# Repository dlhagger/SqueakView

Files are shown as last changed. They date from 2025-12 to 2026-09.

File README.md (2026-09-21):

# SqueakView

SqueakView is a scientific FLIR capture, behavior logging, and YOLO26 pose
inference application for the NVIDIA Jetson Orin Nano. The current platform is
JetPack 7.2.1, CUDA 13.2, TensorRT 10.16, and DeepStream 9.1 using the
PyServiceMaker Pipeline API.

The current development baseline is one FLIR camera at 1440×1080 and 30 FPS,
with optional RP2040 serial triggering/logging and a batch-1 TensorRT pose
model. Generated engines are device-specific and are built locally on the
Jetson. The GUI's wider numeric ranges permit development experiments; they do
not imply scientific qualification. The checked-in production matrix supports
only its explicitly listed 1440×1080/30 FPS profile, and that profile remains
unqualified until the acceptance gates below are completed.

## Data-flow policy

SqueakView treats the compressed camera recording as scientific ground truth:

- The recording branch is non-leaky. It never intentionally drops a frame.
- Inference is downstream-leaky so slow inference cannot backpressure recording.
- GUI preview is leaky because it is only an operator spot check.
- Every recorded frame is reconciled against a durable source audit and the
  recording admission ledger.
- Missed live inference can be recovered later on downstream compute by
  replaying `raw.mp4`.

`raw.mp4` is H.264-compressed with CPU `x264enc`. It is authoritative, but not
an uncompressed sensor dump. CPU encoding is intentional because the Orin Nano
does not provide the hardware encoder used by larger Jetson modules.

## Acquisition and analysis boundary

The Jetson is the acquisition appliance. Normal shutdown validates the final
MP4 sample count against the durable capture, recording-admission, and
controller totals without rereading the multi-gigabyte ledgers. Frame-level
reconciliation, controller timing alignment, exploratory notebooks,
production-scale analysis, video transcoding, and offline re-inference are
explicit analysis work and do not block safe recording closure.

The current transfer procedure is a manual copy of the complete finalized run
directory. Keep the Jetson original until the DGX copy has been inspected and
validated. See [data_viz/README.md](data_viz/README.md) for the run contract,
manual transfer checklist, DGX directory layout, alignment commands, and
downstream data-handling rules. Resumable `rsync` transfer is flagged for a
future release and is not part of the initial workflow.

## Repository layout

```text
build_engine/                    Project Setup model-builder documentation
configs/                         Runtime tracker configuration
native/flir_gst_source/          Scientific Spinnaker GStreamer source
native/nvdsinfer_custom_impl_yolo/ DeepStream YOLO26 detector parser
resources/project_template/      New-project tasks, qualification, and model seeds
squeakview/apps/inference/        Live and offline PyServiceMaker pipelines
squeakview/apps/operator/         Qt operator GUI and run lifecycle
squeakview/common/                Run, profile, serial, and dashboard utilities
scripts/preflight.sh              Device/model readiness checks
scripts/align_run_outputs.py      Camera, video, inference, and TTL alignment
data_viz/README.md                Jetson-to-DGX transfer and analysis workflow
data_viz/analysis_demo_viz.ipynb Scientific run analysis and visualization
tests/                            Pure-Python and on-device pipeline tests
```

Application code and scientific data have separate ownership. Each project owns
its `runs/`, `models/`, `model_sources/`, `tasks/`, `profiles/`, and
`qualification/` directories outside this repository. The application install
is replaceable and normal operation does not write to it. New projects receive
independent copies of MouseHouse v2, stock YOLO pose, the default task, and the
qualification templates from `resources/project_template/`.

To build a model, put any additional `.pt` checkpoint and dataset YAML together
in a direct child of the project's `model_sources/` directory. Launch
SqueakView, select the project, and use the pre-acquisition **Project Setup**
screen. Generated device-specific packages are published only into that
project's `models/` directory.

## Install and update layout

Keep the Git checkout in Documents and let SqueakView create projects beside it:

```text
~/Documents/
├── SqueakView/           application code, `.venv`, and native builds
└── SqueakView Projects/  project settings, models, profiles, and runs
```

For a fresh checkout:

```bash
cd "$HOME/Documents"
git clone https://github.com/dlhagger/SqueakView.git
cd SqueakView
uv venv --python 3.12 --system-site-packages
uv sync
bash scripts/setup_jetson.sh
```

Reboot after the one-time setup. To update later, finish any active run, close
SqueakView, and update only the application checkout:

```bash
cd "$HOME/Documents/SqueakView"
git pull --ff-only
uv sync
bash scripts/build_native.sh
.venv/bin/python -m pytest -q
bash squeakview.sh
```

Routine application updates do not require a reboot. Git, dependency, and
native-build operations never target `~/Documents/SqueakView Projects`, so they
cannot replace scientific data. See [the project workflow](docs/PROJECT_WORKFLOW.md)
for project creation, model building, rollback, and acceptance checks.

## Jetson device setup

Run the device setup once as the desktop user who will launch SqueakView:

```bash
bash scripts/setup_jetson.sh
```

The script installs NVIDIA's Jetson FFmpeg package (including `ffprobe`) and
the complete GStreamer runtime/plugin and native build prerequisites, builds
both the FLIR GStreamer source and the
DeepStream YOLO parser against the installed CUDA toolkit, and adds that user
to the `dialout` group for RP2040/USB serial access. It also creates
`~/Documents/SqueakView Projects` when absent and leaves an existing directory
untouched. It can be launched from any working directory. Reboot after it
completes because a group change cannot affect an already-running login session.
If the whole setup script is invoked through `sudo`, it deliberately drops back
to the desktop user for native compilation so the checkout does not acquire
root-owned build files. Do not run the application itself with `sudo`.

After the one-time privileged setup, checkout updates rebuild their native
components without sudo through `bash scripts/build_native.sh`.

## Platform prerequisites

Install these before setting up the repository:

- JetPack 7.2.1 with CUDA/TensorRT
- NVIDIA DeepStream 9.1 at `/opt/nvidia/deepstream/deepstream`
- FLIR/Teledyne Spinnaker SDK at `/opt/spinnaker`
- [Spinnaker for the JetPack 7.2 series](https://teledyne.app.box.com/s/ccj73r4xu8rusbnu12pytcisbexdchfa)
  is currently distributed as a beta build by Teledyne and is deployed here on
  JetPack 7.2.1.
- GStreamer runtime and development headers
- Jetson Orin Nano specific install of FFmpeg (`scripts/setup_jetson.sh` installs it)
- CMake, a C++ compiler, and `uv`

Typical native-build packages:

```bash
sudo apt install build-essential cmake pkg-config \
  libgstreamer1.0-dev libgstreamer-plugins-base1.0-dev
```

Expected vendor paths:

```text
/opt/spinnaker/include
/opt/spinnaker/lib
/opt/nvidia/deepstream/deepstream/sources/includes
/usr/local/cuda-13.2
```

Override the DeepStream root when necessary:

```bash
export SQUEAKVIEW_DEEPSTREAM_SDK=/opt/nvidia/deepstream/deepstream
```

## Python environment

SqueakView targets Python 3.12 on Linux AArch64. Create the project environment
with access to the JetPack/DeepStream system packages:

```bash
uv venv --python 3.12 --system-site-packages
uv sync
source .venv/bin/activate
```

The project uses CUDA 13.2 PyTorch wheels and a CUDA 13 ONNX Runtime index as
configured in `pyproject.toml`. DeepStream 9.1 supplies PyServiceMaker through
the system Python installation.

The live tensor decoder currently uses PyTorch DLPack to read DeepStream tensor
metadata. DeepStream performs TensorRT inference; ONNX Runtime is used by model
export tooling rather than by the live pipeline.

## Build native components

### FLIR GStreamer source

```bash
cmake -S native/flir_gst_source -B native/flir_gst_source/build
cmake --build native/flir_gst_source/build -j
GST_PLUGIN_PATH=$PWD/native/flir_gst_source/build gst-inspect-1.0 flirspinsrc
```

This produces `native/flir_gst_source/build/gstflirspinsrc.so`.

`flirspinsrc` uses Spinnaker directly and emits `GRAY8` frames. Its scientific
metadata profile records the FLIR chunk frame ID, acquisition-local image ID,
camera timestamp, exposure, gain, black level, ROI, pixel format, sequencer
state, CRC, image status, payload size, host clocks, camera/host clock
correlation, temperature, and transport counters. Incomplete images fail the
acquisition instead of being silently accepted.

See [native/flir_gst_source/README.md](native/flir_gst_source/README.md) for the
standalone camera smoke tests and complete metadata contract.

### DeepStream YOLO parser

Build against the CUDA version installed on the device:

```bash
make -C native/nvdsinfer_custom_impl_yolo CUDA_VER=13.2 -j
```

This produces:

```text
native/nvdsinfer_custom_impl_yolo/libnvdsinfer_custom_impl_Yolo.so
```

The library satisfies DeepStream's detector parser ABI for the YOLO26
end-to-end output. The PyServiceMaker `Yolo26PoseTensorOperator` is the
authoritative pose decoder: it reads `output0` tensor metadata, applies the
model-sidecar thresholds, restores source-image coordinates, and hands objects
and keypoints to NvDCF tracking and CSV persistence.

Rebuild both native components after JetPack, CUDA, TensorRT, DeepStream, or
Spinnaker upgrades.

## Build a YOLO26 pose model package

Fresh projects contain model inputs but no generated TensorRT packages. Launch
SqueakView normally:

```bash
bash squeakview.sh
```

After project selection, Project Setup defaults to the project-owned MouseHouse
v2 source package. Its isolated builder worker holds the project's exclusive
writer lock and:

1. Reads standard class names, keypoint names, and keypoint shape from the YAML
   and checkpoint without modifying the YAML.
2. Passes the YAML to `Ultralytics.export(data=...)`.
3. Exports an NMS-free, end-to-end FP16 or FP32 TensorRT engine on the target
   Jetson using Ultralytics `nms=False`.
4. Strips the Ultralytics metadata prefix to produce the raw TensorRT plan
   expected by DeepStream.
5. Validates ONNX and TensorRT input/output shapes.
6. Writes and validates a schema-3 model package with a schema-2 pose sidecar.
7. Exits and releases its CUDA context before the acquisition supervisor starts.

Generated layout:

```text
$SQUEAKVIEW_PROJECT/models/<model_name>/
  weights/<source>.pt
  onnx/<model>_<precision>_b<batch>.onnx
  engines/<model>_<precision>_b<batch>.engine
  labels/classes.txt
  labels/labels.txt
  configs/<model_name>.txt
  configs/<model_name>.pose.json
  validation/import_report.json
  model.yaml
```

The pose sidecar contains tensor geometry, class thresholds, tracking policy, and keypoint labels. SqueakView stores and displays labeled keypoint dots.

TensorRT plan files are device-specific. Build each engine on the Jetson that
will run it. The model package batch size must match the configured camera
count. The currently validated packages and normal GUI workflow are batch 1.
Multi-camera support is planned, you may implement it now at your own risk by
matching the batch size to the number of configured cameras.

Each run manifest records SHA-256 identities for the model manifest, pose
sidecar, ONNX graph, DeepStream config, and TensorRT engine. Production
qualification requires the complete identity set and the exact installed
`nvidia-jetpack` package version is retained with the other platform packages.

See [build_engine/README.md](build_engine/README.md) for builder details.

## Preflight

Select a generated model explicitly and run preflight with the project
interpreter:

```bash
export SQUEAKVIEW_PROJECT="$HOME/Documents/SqueakView Projects/My Project"
PYTHON_BIN=.venv/bin/python \
SQUEAKVIEW_MODEL_NAME=<model_name> \
bash scripts/preflight.sh
```

You can provide the config directly instead:

```bash
PYTHON_BIN=.venv/bin/python \
DS_CFG="$SQUEAKVIEW_PROJECT/models/<model_name>/configs/<model_name>.txt" \
bash scripts/preflight.sh
```

Run the same check remotely:

```bash
ssh -t jetson@<jetson-host> 'cd ~/Documents/SqueakView && export SQUEAKVIEW_PROJECT="$HOME/Documents/SqueakView Projects/My Project" && PYTHON_BIN=.venv/bin/python SQUEAKVIEW_MODEL_NAME=<model_name> bash scripts/preflight.sh'
```

For camera-only testing without inference:

```bash
PYTHON_BIN=.venv/bin/python INFERENCE_ENABLED=0 bash scripts/preflight.sh
```

For a manual check of the configured controller as well, provide its device:

```bash
SQUEAKVIEW_MODEL_NAME=<model_name> SERIAL_ENABLED=1 \
SERIAL_PORT=/dev/ttyACM0 PYTHON_BIN=.venv/bin/python bash scripts/preflight.sh
```

Preflight checks the DeepStream install, required GStreamer elements, the FLIR
plugin and capture-ledger API, NvDCF dependencies, the selected model package,
Jetson memory state, `ffprobe`, and Python imports. It exercises DeepStream
9.1 Stream multiplexer 2 through the same VIC-to-surface-array NVMM path used
by acquisition. Before every recording, it also
creates a temporary 30-frame H.264 clip and fully decodes it through the same
isolated `nvv4l2decoder` used for anomaly escalation. Acquisition is
blocked if the Jetson hardware decoder cannot complete that real decoder
self-test. No readiness result is reused across recordings.

Inference preflight requires a schema-3 engine build identity matching the
current TensorRT, CUDA, Jetson Linux, GPU capability, and device. A schema-2
package remains readable for migration inspection but is blocked from
scientific acquisition; rebuild it from the Project Setup screen.

DeepStream may print plugin-scanner warnings for unused optional plugins when an
OpenTelemetry library is absent. They do not affect SqueakView if every required
element passes preflight. Preflight reports the current `tegrastats` sample for
diagnosis. NVIDIA documents its LFB field as an allocator statistic whose largest
normal block is at most 4 MB, so LFB is not treated as a standalone readiness
threshold.

See [`docs/REFACTOR_PLAN.md`](docs/REFACTOR_PLAN.md) for the staged JetPack 7.2.1
and DeepStream 9.1 modernization plan and the scientific recording invariants.

Note: clearing memory cache and setting the jetson to "cool" thermal profiles are
easily achieved by installing jtop.

## Launch the operator GUI

```bash
bash squeakview.sh
```

The small project chooser appears on every launch and preselects the most
recently opened valid project. You can create a project, browse to another one,
or confirm the preselected project. It creates the default projects parent when
missing and never rewrites an existing one. Project Setup then lets you build or
select the project default model before the supervisor, experiments, or subjects
start. For automation or development, pass an existing project explicitly:
`bash squeakview.sh /absolute/project/path`; Project Setup still appears.

This detached launcher is the production path. It starts a Qt-free supervisor,
which owns the controller, capture, run lock, and finalization while launching
and monitoring the required GUI. If the GUI exits or loses its exclusive IPC
lease during a run, the supervisor stops acquisition and completes fail-closed
finalization; acquisition never continues headlessly. Terminal or VS Code loss
does not end the supervised session. Separate bounded GUI and supervisor logs
are written under `${XDG_STATE_HOME:-$HOME/.local/state}/SqueakView/logs/`;
each mirror is capped at 32 MiB and partial
lines are capped at 64 KiB.
Stop requests are acknowledged immediately by the supervisor. Capture closure
and post-run analysis continue in a supervisor-owned worker while the responsive
GUI receives lifecycle events and heartbeats; run duration therefore cannot
turn a slow alignment pass into an IPC timeout or a false GUI-loss failure.
The launcher reports success only after the supervisor has authenticated the
GUI's IPC connection; an early GUI failure or connection timeout returns
nonzero with the supervisor log path. The bounded wait defaults to 35 seconds,
slightly longer than the supervisor's 30-second GUI connection deadline,
and can be adjusted with `SQUEAKVIEW_LAUNCH_TIMEOUT_S`.

The lease is renewed only by a Qt-main-loop timer, so a frozen GUI is treated
as lost even if its background IPC thread still exists. The DeepStream capture
child also uses Linux parent-death signaling, preventing a hard supervisor
failure from leaving the sessionized capture process alive. A hard owner failure
cannot perform ordered finalization, and that run must not pass qualification.

The RP2040 is a separate safety boundary. This repository currently contains no
versioned controller firmware or qualified negotiated watchdog, so an
independently powered controller may continue generating TTL pulses after total
Jetson/supervisor failure. Triggered scientific deployment requires a
firmware-level, hardware-qualified lease/watchdog before that failure mode can
be claimed safe. The proposed wire contract, host integration requirements, and
electrical acceptance evidence are defined in
[`docs/CONTROLLER_WATCHDOG_PROTOCOL.md`](docs/CONTROLLER_WATCHDOG_PROTOCOL.md).
The host includes an explicitly opt-in, production-disqualified experimental v1
implementation for firmware development and bench testing. Legacy behavior is
unchanged by default, and the application does not claim watchdog protection.

The complete project layout, model-build handoff, path ownership rules, and
short on-device acceptance pass are in
[`docs/PROJECT_WORKFLOW.md`](docs/PROJECT_WORKFLOW.md).

Direct GUI startup is blocked by default because it bypasses durable
supervision. For foreground development only, opt in visibly and provide an
explicit project:

```bash
SQUEAKVIEW_PROJECT="/absolute/path/to/My Project" \
SQUEAKVIEW_ALLOW_INPROCESS_BACKEND=1 \
.venv/bin/python squeakview_gui.py
```

Scientific operation must use `bash squeakview.sh`. Serial capture defaults to
`/dev/ttyACM0` at 115200 baud; choose the actual device shown by
`ls /dev/ttyACM*`.

Useful path overrides:

```bash
export SQUEAKVIEW_DEEPSTREAM_SDK=/opt/nvidia/deepstream/deepstream
export SQUEAKVIEW_PROJECTS_DIR="$HOME/Documents/SqueakView Projects"
bash squeakview.sh /absolute/path/to/a/project
```

The supervised backend launches inference first. For free-running capture, the
GUI reports recording after the PyServiceMaker pipeline reaches `PLAYING`. In
triggered mode, it sends `START` only after that readiness signal and reports
recording only after the first controller TTL is observed. The default readiness
timeout is 30 seconds and can be changed with
`SQUEAKVIEW_INFERENCE_READY_TIMEOUT`.

Serial logging may remain enabled during free-running capture, but its data are
auxiliary and no trigger/frame alignment is claimed. Exact TTL alignment is a
mandatory finalization and qualification gate only when both serial logging and
camera triggering are enabled under the legacy controller protocol. Protocol v2
is the production default for controller-backed GUI runs. A deliberate
`SQUEAKVIEW_CONTROLLER_PROTOCOL=legacy` override remains available only for
non-production bench development with older firmware.

Protocol v2 is negotiated before the clock preflight and capture launch. The
idempotent negotiation supports a freshly booted v1 controller and a controller
that remained in v2 after an earlier run; idle `TIME_SYNC` and `SET_RTC`
responses then use reliable v2 framing. Controller frames are CRC checked and stored, with an `fsync`, in
`diagnostics/controller_v2.jsonl` before SqueakView sends a cumulative
`ACK_EVENTS`. The controller can then release the acknowledged RAM records.
Camera timing uses `CAMERA_EPOCH`, periodic `CAMERA_CHECKPOINT`, and
`CAMERA_STOP` rather than two serial lines per frame. A transport integrity
fault, conflicting replay, unrecoverable sequence gap, or controller reboot
during a run fails the run closed. `serial.csv` remains a compatibility export
of decoded payloads; the JSONL journal is the v2 source of truth.

Run the physical-controller qualification before production use:

```bash
uv run mousehouse-protocol-v2-test /dev/ttyACM0 \
  --fps 30 --duration 60 --withhold-acks 5 \
  --request-resend --status --correct-clock --verbose \
  --output /tmp/mousehouse-protocol-v2-test
```

`--correct-clock` explicitly authorizes one idle `SET_RTC` if the initial clock
burst is outside tolerance. The tool always collects and verifies a fresh
seven-sample burst after correction before it may start acquisition.

The controller remains in v2 until it reboots. SqueakView safely rejoins that
mode on subsequent GUI runs, so a reboot between ordinary runs is unnecessary.
Reboot after a standalone qualification before using a host build that predates
this idempotent negotiation support.
The separate `--exercise-overflow-failsafe` mode intentionally fills the queue,
invalidates and stops the run, and also requires a reboot. Do not use it during
an experiment.

The durable backend, not the GUI, owns the required preflight gate. It records a
hashed, structured result in both run status and manifest metadata; a missing
FFmpeg check, skipped/failed preflight, or indeterminate automatic-suspend
policy cannot qualify as scientific production. This also prevents direct IPC
clients from bypassing the check.

For every controller-backed experiment, startup also validates the MouseHouse
controller RTC through the already-open serial transport before capture is
launched or controller `START` is sent. The controller uses the PCF8523 as its
sole RTC. Never attach a DS3231 at the same time: both chips have the fixed I²C
address `0x68`. SqueakView first requires the Jetson to report NTP
synchronization, then collects seven `TIME_SYNC` exchanges approximately 100 ms
apart. All seven must report `RTC_VALID`; the median offset of the three
lowest-round-trip samples must be within ±1.5 seconds.

If the clock is invalid or outside tolerance, acquisition remains blocked. RTC
correction is available only when **Allow one pre-run controller RTC correction**
was explicitly enabled in run configuration. SqueakView then sends one
whole-second `SET_RTC`, requires its acknowledgement, and validates a completely
new seven-sample burst. An already-passing clock is never corrected. Validation
and correction are prohibited while a controller session or feed is active;
`DEVICE_BUSY`, timeouts, malformed responses, and NACKs all fail closed. The
complete record is saved as `diagnostics/clock_validation.json`, referenced by
run status and `run_manifest.json`, and summarized in the GUI's Clock Preflight
section.

The RTC establishes UTC only before the experiment. During acquisition, event
timestamps remain anchored to the RP2040 monotonic clock; SqueakView performs no
continuous RTC synchronization and does not alter session timestamp formats.

Startup and the capture child enforce the same free-space reserve (1 GB by
default). During long runs the child rechecks it every five seconds and requests
a fatal but orderly EOS/container close before the filesystem is exhausted.
Set a larger experiment-appropriate reserve with
`SQUEAKVIEW_MIN_RUN_FREE_BYTES`; `SQUEAKVIEW_STORAGE_CHECK_INTERVAL_S` controls
the check interval. Both resolved values are recorded in `run_manifest.json`.

Only one SqueakView process may own scientific acquisition at a time. The
backend holds an OS-managed lock in the run store from pre-start through final
status persistence. A second GUI receives an explicit refusal; a crashed
process releases the lock automatically, so the presence of the small lock file
alone does not indicate an active run.

The timeout is a maximum wait for pipeline readiness, not a fixed warm-up delay.
Reducing it may reject a healthy pipeline that needs longer to load the engine
and enter `PLAYING`.

The run header remains fixed while the operator workspace is composed from
native Qt cards. Open **Layout** while idle to unlock card dragging/floating,
save the current arrangement immediately, or restore the versioned default;
card dividers remain resizable, and a clean GUI close also saves the current
arrangement. Card movement and reset are locked during startup, recording, and
finalization, while explicit Save remains available. Right-click any card title
to open Qt's unified checklist for showing or hiding every card, including Live
Task State and Operator Events. The capture-health panel
shows recording backlog, camera transport health, frame/drop counters, and the
current stop/finalization stage. Run identity and elapsed state remain visible
while the independent post-run finalizer is working.

The capture child's DeepStream output is also retained in
`diagnostics/deepstream.log` inside each run. This log is capped at 64 MiB so a
verbose debug profile cannot consume storage without bound; the operator log
continues after the cap is reached. With
`SQUEAKVIEW_DEEPSTREAM_DEBUG_PROFILE=1`, the run manifest records the profile
and any NVIDIA frame/component latency output is retained in that diagnostic
log. The environment variables alone do not prove that a custom Service Maker
graph emits latency records. The qualification exception therefore fails
unless a bounded scan finds both NVIDIA's structured `Source id`/`Frame_num`/
`Frame latency` record and its `Comp name`/`Component latency` record, with
finite values, and the diagnostic log was not truncated.
The profile remains qualification-only until paired debug-off/debug-on runs
establish its acquisition overhead. Debug-profile runs are explicitly marked
non-production. Qualify only the debug-on member with the narrow exception:

```bash
export SQUEAKVIEW_PROJECT="/absolute/path/to/My Project"
.venv/bin/python scripts/qualify_run.py "$SQUEAKVIEW_PROJECT/runs/<debug-off-run>"
.venv/bin/python scripts/qualify_run.py "$SQUEAKVIEW_PROJECT/runs/<debug-on-run>" --allow-debug-profile
```

After both matched runs pass `scripts/qualify_run.py`, compare their bounded
recording and system metrics with:

```bash
.venv/bin/python scripts/compare_debug_overhead.py \
  "$SQUEAKVIEW_PROJECT/runs/<debug-off-run>" "$SQUEAKVIEW_PROJECT/runs/<debug-on-run>" \
  --thresholds "$SQUEAKVIEW_PROJECT/qualification/<approved-overhead-limits>.yaml" \
  --output "$SQUEAKVIEW_PROJECT/qualification/debug-overhead.json"
```

Follow the complete non-automating acquisition and evidence-retention procedure
in [docs/qualification/DEBUG_OVERHEAD_PROTOCOL.md](docs/qualification/DEBUG_OVERHEAD_PROTOCOL.md).
The checker accepts `--case-id` to require both GUI-launched runs to carry the
same backend-enforced qualification binding, and rejects nonterminal or
non-supervised runs.

The comparison fails closed unless the capture, inference, preview, model,
power-mode, application-commit, and complete platform/package/native-plugin
identities match and the manifests explicitly identify opposite debug-profile
states. It compares all five model content
hashes and the engine build identity, verifies that neither cached qualification
summary is stale against its hashed source artifacts, requires the same exact
validated limits file, and requires duration to differ by no more than the
larger of five seconds or 1% of the longer run (both tolerances are CLI options).

Without `--thresholds`, a comparable report remains `incomplete`; the tool does
not invent empirical limits. A version-1 threshold file must set `approved:
true` and provide every reported metric under `metrics`, with at least one
nonnegative `max_increase` or `max_percent_increase` per metric. These bounds
apply only to increases from debug-off to debug-on. An approved profile makes
the report and command exit explicitly passed or failed.

## Live DeepStream pipeline

The validated single-camera path is:

```text
flirspinsrc → GRAY8 caps → tee
  ├─ record queue (120 frames / 4 s minimum, non-leaky)
  │    → x264enc (native GRAY8) → h264parse → mp4mux → raw.mp4
  └─ inference queue (32 frames, downstream-leaky)
       → VIC nvvideoconvert/surface-array NVMM-NV12 → nvstreammux v2
       → nvinfer/TensorRT → Python YOLO26 pose decode
       → CUDA NvDCF → [nvosdbin → nvstreamdemux when preview is enabled]
       → preview admission identity → preview queue (1 frame, downstream-leaky)
       → preview delivery identity → nvunixfdsink
       → Qt nvunixfdsrc preview
```

The FLIR transport is configured with at least 64 host buffers (two seconds at
30 FPS), and the record queue intentionally backpressures rather than discarding
data. Recording backlog is sampled in `diagnostics/recording.csv`; a sustained
three-second backlog fails the run before the four-second queue can fill. If CPU
encoding cannot sustain acquisition, the run therefore stops with explicit
evidence instead of silently producing a plausible but incomplete video.

This contract proves temporal frame completeness, not pixel-lossless storage.
The current `x264enc` profile is bitrate-controlled H.264 with one reference
frame, adaptive quantization disabled, no B-frames, and no lookahead. It is explicitly
recorded as `pixel_fidelity: lossy` in `run_manifest.json`. Do not use it for an
experiment requiring exact source pixels until a separately named lossless/raw
profile has been implemented and throughput-qualified.

SqueakView fails a run explicitly when it cannot preserve timing and data
integrity. It does not silently continue with an incomplete but plausible video.
The current production candidate has completed a validated 16-hour,
1,707,205-frame run at 1440×1080 and 30 FPS with zero recording drops, frame
gaps, inference skips, or TTL mismatches.

The GUI/runtime can construct multiple camera branches, producing `raw.mp4` for
camera zero and `raw_camN.mp4` for additional cameras. Multi-camera inference
also requires a batch-N model package and has not received the same scientific
validation as the single-camera path. 

Multi-camera operation remains an advanced configuration and should not be used
for production acquisition until it receives equivalent long-run validation.

SqueakView uses the CUDA NvDCF tracker in `configs/tracker_mouse_nvdcf.yml`.
Jetson Orin Nano has no PVA hardware, so a PVA/VPI tracker profile is not an
acceleration option. Tracker thresholds remain model- and experiment-specific.

## Run outputs and frame identity

Runs are stored under:

```text
runs/<experiment>/<subject>/<subject>_<timestamp>_<shortid>/
```

Important outputs include:

```text
raw.mp4                         Authoritative compressed camera recording
frames.csv                      Authoritative recorded-frame ledger
serial.csv                      RP2040 events, TTLs, markers, and host clocks
objects.csv                     Detector/tracker object rows
keypoints.csv                   Normalized pose keypoints
run_manifest.json               Configuration, model identity, and artifacts
run_status.json                 Lifecycle, reconciliation, and validation
alignment_summary.json          Compact frame/video/controller audit
diagnostics/camera.csv          Temperature and transport health samples
diagnostics/recording.csv       Recording queue and encoder telemetry
diagnostics/system.csv          Capture-owned bounded Jetson resource telemetry
diagnostics/errors.csv          Camera gaps, CRC, and incomplete-frame events
diagnostics/camera_runtime.json Camera identity and clock calibration
diagnostics/deepstream.log      Size-bounded capture/DeepStream child output
diagnostics/post_run.log        Finalizer subprocess log
diagnostics/preview_admission*.csv Source IDs entering each leaky preview queue
diagnostics/preview_delivery*.csv  Source IDs delivered after preview shedding
config/task.yaml               Immutable run-local task definition snapshot
```

`frames.csv` is written live by the FLIR source and is the source of truth for
captured frame identity. It contains one row per emitted source buffer. Stop
uses bounded tail reads and the MP4 sample table; it does not rebuild this file.
Validation requires its final index to agree with the non-leaky recording
admission ledger and the finalized MP4 sample count.
The camera telemetry, error ledger, and runtime snapshot are also written by
the source while acquisition is active, rather than reconstructed at shutdown.
`objects.csv` is the single object-observation table; track summaries are
derived from it when analyzed.
Once a run reaches a terminal state, its acquisition, model, Git, and storage
provenance in `run_manifest.json` is immutable. Later bottle entry updates only
the bottle summary, artifact inventory, and manifest update timestamp.

Source, admission, and inference ledgers (`capture_cam*.jsonl`,
`record_admission*.csv`, and `inference/`) are retained after successful
validation as primary scientific provenance. Only transient finalizer progress
state is cleaned up. This costs additional storage but preserves the evidence
needed to reproduce frame reconciliation and diagnose a later integrity issue.
Routine finalization reads the bounded MP4 sample tables without parsing or
decoding the complete H.264 stream. It requires the sample-size, timing, and
sample-to-chunk totals to agree with the live frame manifest, source ledger,
recording-admission ledger, and controller count. Full decode remains an
explicit qualification option, not an automatic shutdown fallback.

Generate a bounded-memory qualification summary after finalization with:

```bash
export SQUEAKVIEW_PROJECT="/absolute/path/to/My Project"
.venv/bin/python scripts/qualify_run.py "$SQUEAKVIEW_PROJECT/runs/<experiment>/<subject>/<run>"
```

The checked-in JetPack 7.2.1 limits profile is intentionally marked
measurement-only. Results remain `incomplete` until sustained baseline runs are
used to approve explicit thermal, resource, telemetry-coverage, and recording
limits. Qualification writes `qualification_summary.json`; it never changes the
capture-validity decision in `run_status.json`. The summary hashes the manifest,
status, limits, primary recording artifacts, system telemetry, and every
recording telemetry file it consumed so paired comparisons reject stale or
substituted evidence.
Preview admission and delivery ledgers attribute intentional GUI-preview
shedding by source sequence, camera FrameID, and PTS. Missing preview evidence
fails preview-enabled qualification, but preview loss and preview-observability
failure never invalidate the independent scientific recording.

The full 24-cell short/one-hour/full-duration matrix is defined in
`$SQUEAKVIEW_PROJECT/qualification/matrix.v1.yaml` across inference, preview, and 25 W/MAXN_SUPER
modes. The complete operator procedure, including hardware prerequisites,
measurement-only limits, durable campaign outputs, and recovery from incomplete
cells, is in [docs/qualification/QUALIFICATION_WORKFLOW.md](docs/qualification/QUALIFICATION_WORKFLOW.md).
Enumerate the canonical IDs and create a non-overwriting assignment checklist:

```bash
.venv/bin/python scripts/qualify_matrix.py --list-cases
.venv/bin/python scripts/qualify_matrix.py \
  --init-assignments "$SQUEAKVIEW_PROJECT/qualification/assignments.local.yaml"
```

Print the next unassigned case, its exact environment, and a copyable terminal
launcher command without changing the checklist or starting hardware:

```bash
.venv/bin/python scripts/qualify_matrix.py \
  "$SQUEAKVIEW_PROJECT/qualification/assignments.local.yaml" \
  --next-case
```

After each completed run, record its case with `--assign`, then evaluate matrix
coverage with:

```bash
.venv/bin/python scripts/qualify_matrix.py \
  "$SQUEAKVIEW_PROJECT/qualification/assignments.local.yaml" \
  --assign '<case-id>' '/absolute/path/to/completed/run'
.venv/bin/python scripts/qualify_matrix.py "$SQUEAKVIEW_PROJECT/qualification/assignments.local.yaml"
```

For the acquisition itself, export
`SQUEAKVIEW_QUALIFICATION_CASE_ID='<case-id>'` before launching the operator.
The backend rejects factor, preview, or exact nvpmodel mismatches before run
creation and persists the binding. `SQUEAKVIEW_QUALIFICATION_MATRIX` may point
to a deliberately selected alternate versioned matrix. Ordinary runs remain
unbound when the case variable is unset; they cannot later be substituted into
the production matrix.

The assignment YAML must be a stable regular file; its read is size-bounded and
duplicate-key rejecting, and it rejects case IDs that are not present in the
selected matrix. The same stable, bounded regular-file policy applies to limits,
matrix, failure-plan, and debug-threshold inputs.

Unassigned cells and runs evaluated against measurement-only limits remain
`incomplete`; factor mismatches or failed run qualification fail the cell. The
matrix also fails closed on dirty/non-production runs and requires every cell
to use the same application commit and complete device/package/native-plugin
identity, including inference-off cells. Power modes must match the exact
labeled `nvpmodel` mode. Every inference-enabled cell must use the same hashed
model/engine identity.

After all cells pass against reviewed limits, create and verify the bounded,
content-addressed campaign inventory described in the workflow with
`scripts/archive_qualification_campaign.py`. The tool does not copy or modify
run data; it rejects incomplete campaigns and verifies the separately copied
archive tree byte-for-byte.

The destructive bench procedure for validating behavior after sudden input
power loss is documented in
[`docs/qualification/HARD_POWER_LOSS_PROTOCOL.md`](docs/qualification/HARD_POWER_LOSS_PROTOCOL.md).
The gated boundary-fault procedure and supported plan schema are documented in
[`docs/qualification/FAILURE_INJECTION_PROTOCOL.md`](docs/qualification/FAILURE_INJECTION_PROTOCOL.md).

The FLIR chunk `FrameID` is stored as `camera_frame_id` and increments for every
acquired image. The legacy aligner derives a per-run offset between that hardware
frame sequence and RP2040 `CAMERA_HIGH` counts. Protocol-v2 runs preserve camera
epoch/checkpoint/stop anchors for later pandas-based alignment on the analysis
device without emitting per-frame controller edges.

On stop, SqueakView asks the controller to stop before draining DeepStream and
keeps the serial reader open for final acknowledgements. After the capture
process confirms EOS and closes `raw.mp4`, the shutdown validator reads the
last monotonic indices from the capture and non-leaky recording-admission
ledgers, reads the MP4 sample-size/timing/sample-to-chunk/chunk-offset tables,
and requires all totals (plus the controller total when triggered) to agree.
These are bounded tail/table reads; normal shutdown does not hash or decode the
complete video and never rebuilds `frames.csv`. Legacy triggered runs then
generate the controller/camera alignment summary automatically from the
already-written manifest and serial ledger. Protocol-v2 runs validate recording
and acquisition counts on-device and leave detailed controller/camera alignment
to the analysis workflow. Structural errors and count mismatches fail directly.
Set
`SQUEAKVIEW_VIDEO_VALIDATION_FULL_DECODE=1` for qualification runs that require
every pixel frame to be decoded. Add `SQUEAKVIEW_VIDEO_VALIDATION_AB_VERIFY=1`
to run both full decoders and reject any count disagreement.
Bottle intake is calculated as initial minus final weight. A final weight above
the initial weight is saved but shown as a plausibility warning.

To rerun the legacy bounded-memory recovery reconstruction explicitly:

```bash
.venv/bin/python -m squeakview.apps.inference.post_run /path/to/run \
  --camera-count 1 --full-analysis --enable-infer --align
```

The command rebuilds `frames.csv` from recovery ledgers and performs the deeper
inference/object reconciliation. Normal runs do not need this command because
capture writes `frames.csv` live and Stop generates `alignment_summary.json`.

## Analyze a run

Copy the complete finalized run directory to the DGX Spark before beginning
downstream analysis. The source copy should remain unmodified; figures, tables,
new alignment results, and future re-inference outputs belong in a separate
analysis-results directory.

The visualization notebook is a short-run example of the current tables and
their timing relationships, not the production engine for a full-length run.
Launch it on the DGX from an analysis environment:

```bash
jupyter lab data_viz/analysis_demo_viz.ipynb
```

Set `RUN_DIR` in the first code cell to an explicit copied run. Leave
`INFERENCE_RESULT = "live"` to inspect the acquisition-time objects and
keypoints.

The notebook reports acquisition and inference health, TTL/PTS timing,
behavioral events, mapping provenance, NvDCF tracks, keypoint confidence, event-
locked object data, and an optional exact-frame `raw.mp4` preview with boxes and
keypoint dots.

The current notebook loads canonical CSVs into memory and is intended for short
or sampled demo runs. Do not run it on the acquisition Jetson or point it at a
complete 16-hour run. See [data_viz/README.md](data_viz/README.md) for the full
workflow and source-data rules.

## Offline re-inference (downstream only)

Do not run offline re-inference on the acquisition Jetson. On a downstream
system with a compatible TensorRT engine, launch it with:

```bash
python -m squeakview.apps.inference.offline RUN_DIR --cfg MODEL_CONFIG \
  --out-dir NEW_DERIVED_DIRECTORY
```

The command keeps the long-run frame ledger in a temporary disk-backed index
and performs one authoritative decode. It does not do a second full-file
FFprobe count pass: the in-pipeline audit requires contiguous decoded ordinals,
rejects frames beyond the ledger immediately, and only publishes a complete
manifest after decoder EOS and an exact final count. A small supervisor process
owns the native Service Maker worker. SIGINT/SIGTERM requests orderly teardown;
if native `stop()`/`wait()` remains blocked for 45 seconds, the supervisor
terminates the isolated worker process group and returns failure. Linux
parent-death containment also kills the worker if the supervisor itself dies.
Derived output never overwrites the acquisition `raw.mp4`, `objects.csv`, or
`keypoints.csv`.
See [data_viz/README.md](data_viz/README.md) for downstream source-data rules.

## Diagnostics

Show optional DeepStream plugin warnings that the GUI normally filters:

```bash
SQUEAKVIEW_SHOW_PLUGIN_WARNINGS=1 bash squeakview.sh
```

Request fan control when the current user has the required privileges:

```bash
SQUEAKVIEW_SET_FAN=1 bash squeakview.sh
```

Temporarily bypass GUI preflight only for deliberate diagnosis:

```bash
SQUEAKVIEW_SKIP_PREFLIGHT=1 bash squeakview.sh
```

Any run started with this bypass is explicitly marked non-production and cannot
pass qualification.

Qualification-only failure injection requires both an explicit safety gate and
a versioned JSON plan. Every such run is labeled `production_eligible: false`
in status and manifest metadata. Never enable this for data collection:

```bash
SQUEAKVIEW_ENABLE_FAILURE_INJECTION=1 \
SQUEAKVIEW_FAILURE_PLAN=/absolute/path/to/failure-plan.json \
bash squeakview.sh
```

Supported boundaries are the FLIR source, non-leaky recording queue, encoder,
muxer, filesink/disk, serial controller, and shutdown supervisor. The plan is
rejected if the gate is absent, its schema is unknown, or its target/kind is
unsupported.

The `/dev/full`-based `filesink/disk_full` case is intentionally immediate: it
fails on the selected sink's first write and requires `after_frames: 1` as a
sentinel. It does not simulate one successful recorded frame followed by disk
exhaustion. Use `filesink/error` when a delayed filesink-boundary fault is
required.

To exercise the required preview-off qualification cell while still using the
GUI as the operator interface, launch with `SQUEAKVIEW_DISABLE_PREVIEW=1`. This
omits the preview branch from the capture graph; it does not run the app
headlessly:

```bash
SQUEAKVIEW_DISABLE_PREVIEW=1 bash squeakview.sh
```

Run the test suite without changing the environment:

```bash
.venv/bin/python -m pytest -q
```

## Git policy

Commit source code, tests, documentation, notebooks without saved outputs,
configuration, native build recipes, and shipped project-template model inputs.
Do not commit device-local or generated state:

```text
.venv/
models/
profiles/
runs/
native/flir_gst_source/build/
native/**/*.o
native/**/*.so
```

A fresh clone should contain everything needed to rebuild the native plugins
and local model packages on a compatible Jetson, but no device-specific engine
or experimental run output.

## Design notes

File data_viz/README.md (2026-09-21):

# Run Transfer and Analysis Workflow

SqueakView separates acquisition from downstream scientific analysis. The
Jetson is the acquisition appliance; the DGX Spark is the analysis system.

## System Responsibilities

The Jetson:

- Captures `raw.mp4` and the canonical CSV tables.
- Runs the bounded post-run integrity audit required to finalize a run.
- Records acquisition, model, software, and validation provenance.
- Does not run exploratory notebooks, full-run downstream analysis, video
  transcoding, or offline re-inference.

The DGX Spark:

- Stores a verified copy of each finalized run.
- Builds the protocol-v2 frame/controller timeline from durable camera anchors.
- Runs notebooks, statistics, visualization, and project-specific analysis.
- Stores every derived result outside the copied source run.

The Jetson performs bounded acquisition-integrity and frame-count validation.
Protocol v2 does not build a legacy per-frame TTL alignment on the Jetson;
derived analysis timelines are built on the analysis device. Wait for capture
validation to finish before copying a run.

For the exact frame identities, controller-clock mapping, inference joins, and
large-run processing rules, see [ALIGNMENT_GUIDE.md](ALIGNMENT_GUIDE.md).

## Current Transfer Procedure

The initial workflow uses a manual copy. Transfer automation is intentionally
deferred.

1. Wait until the GUI reports that capture validation and finalization are
   complete.
2. Enter and save final bottle weights when the experiment uses them.
3. Confirm that `run_status.json` contains `"state": "finalized"`.
4. Copy the entire run directory to an external drive, network share, or other
   manually selected destination.
5. Copy that complete directory to the DGX Spark.
6. Keep the original Jetson directory until the DGX copy has been inspected and
   validated.

Copy the directory; do not move it off the Jetson during this first transfer.
Do not copy a hand-selected subset of files, rename files, flatten the directory,
or transcode `raw.mp4`.

Before using removable media, confirm that it has enough free space and uses a
filesystem that supports files larger than 4 GB, such as exFAT, NTFS, or ext4.
FAT32 cannot hold a normal long-run `raw.mp4`.

Example source directory:

```text
runs/<experiment>/<subject>/<subject>_<timestamp>_<shortid>/
```

## Canonical Run Files

A normal finalized single-camera run contains:

```text
raw.mp4                         Authoritative H.264 camera recording
frames.csv                      One row per recorded frame
serial.csv                      Decoded compatibility export and host markers
objects.csv                     Live detector/tracker observations
keypoints.csv                   Live normalized pose observations
run_manifest.json               Immutable acquisition and model provenance
run_status.json                 Lifecycle and validation result
diagnostics/                    Camera, recording, error, and finalizer records
  controller_v2.jsonl          Durable CRC-checked controller journal
  controller_v2_summary.json   Controller transport integrity summary
config/                         Run-local configuration snapshots
bottle_setup.json               Bottle setup, when used
bottle_measurements.csv         Entered bottle weights, when used
bottle_summary.json             Derived bottle intake, when used
```

Some optional CSVs may contain only their header when no observations or errors
occurred. That is not by itself a failure. `run_status.json` and
`diagnostics/controller_v2_summary.json` determine whether a v2 acquisition
passed validation. `alignment_validated=false` is expected for v2 because the
legacy `CAMERA_HIGH` aligner is intentionally skipped.

## DGX Directory Layout

Keep source data and derived work separate:

```text
/data/squeakview/
  source_runs/
    <run_id>/                   Unmodified copy from the Jetson
  analysis_results/
    <run_id>/
      alignment/
      figures/
      tables/
      reinference/
      logs/
```

Treat `source_runs/<run_id>/` as read-only. Analysis code should write to the
matching `analysis_results/<run_id>/` directory.

## Verify the Copied Run

First inspect `run_status.json` and confirm that the copied video and canonical
tables have the same byte sizes as the Jetson originals. For protocol-v2 runs,
load and validate the copied evidence without changing the source directory:

```python
from pathlib import Path
from data_viz.v2_alignment import load_v2_run

run = load_v2_run(Path("/data/squeakview/source_runs/<run_id>"))
print(len(run.frames), len(run.events), len(run.anchors))
```

The loader rejects incomplete acquisition validation, corrupt or discontinuous
v2 journals, controller boot boundaries, malformed camera anchors, and final
controller/frame count mismatches. Write resulting Parquet tables under the
matching analysis-results directory, never into the copied source run.

Runs recorded without serial input do not contain the RP2040 time base required
by this workflow. For those runs, use the recording and capture reconciliation
results in `run_status.json`.

## Demonstration Notebook

`analysis_demo_viz.ipynb` is an example of the table relationships and plotting
workflow. It is appropriate for short runs and sampled development data. It is
not the production-scale analysis engine for a 16-hour recording.

On the DGX, open the notebook from a Python environment containing Jupyter,
NumPy, pandas, Matplotlib, Seaborn, and IPython:

```bash
jupyter lab data_viz/analysis_demo_viz.ipynb
```

Leave `RUN_DIR = None` to select the newest run referenced by the project
`.latest_run` markers, or set it to a copied source-run path explicitly. Leave
`INFERENCE_RESULT = "live"` to inspect the acquisition-time inference outputs.
The notebook currently reads canonical CSVs into memory, so do not point it at a
full long-duration run unless a suitably sampled copy has been prepared.

Production analyses should use chunked readers, a columnar store, or a database
appropriate to the scientific question, then write figures and tables under
`analysis_results/<run_id>/`.

## Video and Re-inference Rules

`raw.mp4` is the authoritative compressed recording. Downstream tools should
decode it directly and must not replace or overwrite it. A proxy or transcoded
video may be created only as a clearly labeled derived artifact.

Offline re-inference is reserved for the DGX workflow and is not yet the
production long-run path. A DGX-specific TensorRT engine and runtime validation
will be required because TensorRT plans are device-specific. Future re-inference
results must preserve frame ordinal mapping through `frames.csv` and remain
under `analysis_results/<run_id>/reinference/`; they must never overwrite live
`objects.csv` or `keypoints.csv`.

## Future Transfer Release

A future release should add an optional `rsync`-based Jetson-to-DGX transfer
workflow with resumable copying and automated verification. Until that release,
the supported procedure is the complete manual directory copy described above.

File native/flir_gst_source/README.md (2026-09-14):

# FLIR Spinnaker GStreamer Source

Validated GStreamer source element for FLIR/Teledyne cameras through the
Spinnaker C++ SDK.

The element implements SqueakView's current FLIR contract:

```text
flirspinsrc ! video/x-raw,format=GRAY8,width=1440,height=1080,framerate=30/1
```

SqueakView uses this element as its direct FLIR source in the PyServiceMaker
pipeline.

## Build

```bash
cmake -S native/flir_gst_source -B native/flir_gst_source/build
cmake --build native/flir_gst_source/build -j
```

## Inspect

```bash
GST_PLUGIN_PATH=$PWD/native/flir_gst_source/build gst-inspect-1.0 flirspinsrc
```

## Basic Pipeline

With a camera connected:

```bash
GST_PLUGIN_PATH=$PWD/native/flir_gst_source/build \
gst-launch-1.0 -e \
  flirspinsrc camera-index=0 width=1440 height=1080 fps=30 pixel-format=Mono8 exposure-us=10000 trigger=false stream-buffer-count=64 ! \
  video/x-raw,format=GRAY8,width=1440,height=1080,framerate=30/1 ! \
  queue ! fakesink sync=false
```

## DeepStream-Shaped Smoke Test

This was tested on the Jetson with a `FLIR Blackfly S BFS-U3-16S2M` visible to
Spinnaker:

```bash
GST_PLUGIN_PATH=$PWD/native/flir_gst_source/build \
gst-launch-1.0 -e \
  nvstreammux name=m batch-size=1 width=640 height=480 live-source=1 batched-push-timeout=33333 ! \
    fakesink sync=false \
  flirspinsrc num-buffers=5 camera-index=0 width=640 height=480 fps=30 pixel-format=Mono8 trigger=false exposure-us=10000 ! \
    video/x-raw,format=GRAY8,width=640,height=480,framerate=30/1 ! \
    nvvideoconvert compute-hw=2 copy-hw=2 ! \
    'video/x-raw(memory:NVMM),format=NV12,width=640,height=480' ! \
    queue ! m.sink_0
```

The production SqueakView/DeepStream shape is:

```text
flirspinsrc camera-index=0 width=1440 height=1080 fps=30 pixel-format=Mono8 !
  video/x-raw,format=GRAY8,width=1440,height=1080,framerate=30/1 !
  nvvideoconvert compute-hw=2 copy-hw=2 !
  video/x-raw(memory:NVMM),format=NV12,width=1440,height=1080 !
  m.sink_0
```

## Current Scope

- Outputs `GRAY8` frames for DeepStream conversion to NVMM/NV12.
- Uses Spinnaker C++ `GetNextImage()`.
- Supports stable camera serial selection in addition to camera index, width,
  height, fps, pixel format, trigger,
  trigger activation, exposure, gain, timeout, stream buffer handling, and an
  explicit manual Spinnaker host transport buffer count.
- Defaults to `buffer-handling=OldestFirst` and `drop-incomplete=false` so
  scientific acquisition fails/logs instead of silently skipping frames.
- Defaults to `metadata-profile=scientific`, enabling supported FLIR chunks for
  frame ID, timestamp, exposure, gain, black level, ROI, pixel format,
  sequencer state, and CRC.
- Sets `GstBuffer.offset` from FLIR chunk `FrameID`. If the chunk ID is
  unavailable, offset is `GST_BUFFER_OFFSET_NONE`; a sequential value is never
  substituted.
- Treats `Image::GetFrameID()` as an acquisition-local stream frame ID and
  records it separately from the device chunk frame ID.
- Sets `GstBuffer.pts` from the absolute camera timestamp normalized to the
  first frame, with explicit host-monotonic fallback provenance.
- Only when `NVDS_ENABLE_LATENCY_MEASUREMENT` has a recognized truthy value
  (`1`, `true`, `yes`, or `on`, case-insensitive), adds NVIDIA reference-timestamp
  metadata immediately after PTS/DTS using the actual source element name and
  the acquisition-local `source_sequence_index`. The public NVIDIA API returns
  no status; debug qualification therefore still requires emitted latency/FPS
  evidence. With the variable unset or false, no reference metadata is added.
- Attaches `SQUEAKVIEW.FLIR.FRAME_META.v1` before `nvstreammux`. DeepStream
  transforms it to frame-level `NvDsUserMeta` for inference admission auditing.
- Writes the same payload to `capture-log-path` as line-delimited JSON before
  returning each source buffer. This is the verbose recovery ledger.
- Writes canonical frame rows directly to `frame-manifest-path` during capture.
  Shutdown validates that live manifest against the non-leaky recording branch
  and MP4 sample table instead of reconstructing it from the JSON ledger.
- Writes low-rate transport telemetry to `camera-telemetry-path`, camera gap/CRC/
  incomplete-frame events to `error-log-path`, and the resolved camera identity
  and configuration to `camera-runtime-path`. These files are produced live by
  the source; shutdown does not reconstruct them by scanning the capture ledger.
- Captures immediate host receipt clocks, source image layout, actual exposure
  and gain, payload sizes, image status, CRC validation, frame gaps, and source
  health counters.
- Latches the device timestamp at acquisition start against bracketing host
  monotonic and Unix clocks, preserving the raw device tick value and its
  reported nanoseconds-per-tick increment.
- Samples camera temperature and transport-layer health counters about once
  per second and writes them to `diagnostics/camera.csv` using
  the frame's acquisition-side host Unix and monotonic clocks. Missing source
  clocks remain empty rather than being replaced with CSV-write time.
- Uses Spinnaker's typed timeout error and supports a bounded consecutive
  timeout policy. Triggered acquisitions can set the bound to zero.
- Implements `GstBaseSrc` `unlock`/`unlock_stop` so a triggered source blocked
  in `GetNextImage()` returns `GST_FLOW_FLUSHING` during shutdown without
  requiring an additional hardware trigger.
- Converts non-`Mono8` Spinnaker output to `Mono8` before pushing GStreamer
  buffers.
- Copies image memory into a `GstBuffer`; zero-copy/NVMM is a later phase.

## Integration Notes

- `SqueakView` uses this element as the primary FLIR capture backend.
- Preserve raw-video recording in an upstream tee outside this source element;
  the source itself only publishes frames and timing metadata.
- Use `camera-serial` for stable multi-camera rigs; an empty value retains
  index-based selection for compatibility.
- Width, height, exposure, and gain requests are strict: unsupported values
  fail camera startup with the camera's supported range instead of being
  silently clamped.
- `record_admission.csv` is a temporary recovery ledger written at the
  non-leaky recording queue. It is removed after successful finalization.
- `frames.csv` is written directly by this source; shutdown compares its final
  index with the recording-admission ledger and MP4 sample count.
- `diagnostics/errors.csv` records camera-ID gaps, CRC failures, and incomplete
  source images; a header-only file means none were observed. Recording-path
  admission checks independently detect loss between the source and MP4.

The direct source and recording path completed a validated 16-hour,
1,707,205-frame single-camera run at 1440×1080 and 30 FPS with no source gaps,
transport loss, recording drops, or buffer evictions.

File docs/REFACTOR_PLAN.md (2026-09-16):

# SqueakView refactor plan

This plan targets the validated Jetson Orin Nano Super deployment on JetPack
7.2.1 and preserves the scientific acquisition contract while the application
is decomposed. NVIDIA currently lists JetPack 7.2.1 as Jetson Linux 39.2.1,
Ubuntu 24.04, CUDA 13.2.1, cuDNN 9.20.0, TensorRT 10.16.2, and DeepStream 9.1.
DeepStream 9.1 itself was built on the JetPack 7.2 GA/r39.2 baseline, so run
provenance must record exact installed package versions rather than assuming
that the marketing version identifies the complete runtime.

## Non-negotiable scientific contract

The recording path remains upstream of inference and preview:

```text
flirspinsrc -> GRAY8 -> tee -> non-leaky record queue -> x264enc -> MP4
                         `-> leaky inference/preview work
```

- The recording queue must remain non-leaky and must backpressure. A slow
  encoder causes a visible, fatal acquisition fault before the bounded queue
  fills; it must never silently discard a frame.
- Normal shutdown must reconcile the encoded MP4 sample total with the durable
  capture, recording-admission, and controller totals in bounded time. Full
  row-level camera-ID, trigger, inference, and object reconciliation remains a
  required explicit analysis/qualification step rather than blocking safe MP4
  closure.
- Inference and preview may shed work without changing the ground-truth
  recording. Their skips remain measured and attributable by source frame ID.
- Refactors must preserve shutdown order: stop new triggers/acquisition, send
  EOS, drain and finalize the recording container, then validate artifacts.
- Pipeline changes are accepted only after unit tests, failure-injection tests,
  an on-device short run, and a sustained on-device validation run.

Frame completeness and pixel fidelity are separate requirements. This project's
scientific requirement is complete temporal sampling; lossy pixel encoding is
an accepted, explicit constraint. The current
bitrate-controlled H.264 recording can contain every camera frame while still
being lossy at the pixel level. Do not silently replace it with a lossless/raw
profile or segmented recording. Any future change to that decision requires a
new explicit scientific requirement and a separately qualified format.

## Stage 0: freeze behavior and evidence

Status: repository implementation complete; hardware qualification remains in
progress. The shared capture policy, explicit non-leaky queue/QoS
contract, strict ledger parsers, nonzero recording validation, retained source
provenance, controller handshake, process-exit gate, device/native-binary
identity, concurrent atomic metadata writes, fail-closed serial/metadata I/O,
and restart-safe artifact promotion are implemented. Versioned failure plans
are rejected unless the explicit qualification gate is enabled, label the run
non-production, and have been exercised during local development on-device at
the source, recording
queue, encoder, muxer, filesink, and physical disk-write boundaries. The source
fault after 12 frames returned nonzero with exactly 12 source, admission, and
MP4 frames. Encoder, muxer, and filesink faults returned nonzero and left the
container explicitly invalid. The immediate-only `/dev/full` sink
(`filesink/disk_full` with the required `after_frames: 1` sentinel) produced a
propagated `No space left` error and nonzero close; it does not represent one
successfully written frame before exhaustion. The 250 ms queue stall reached the
90-frame fatal backlog threshold with zero telemetry evictions and exited with
code 4 under application control; native drain is deliberately bypassed after
this already-invalid integrity failure because the blocked Service Maker stop
call can retain the Python runtime indefinitely. Explicitly gated serial read,
write, and ledger-write injection plus controller-ACK, capture-exit, and
finalizer-timeout shutdown injection are implemented and unit-tested; their
on-device qualification, hard-power-loss testing, and sustained hardware
qualification remain open.

Those numerical fault-injection observations are operator-reported development
notes. Their raw run directories are not committed and do not count as retained
qualification evidence. Repeat them under the checked-in protocol and retain
immutable run IDs, report hashes, and archive location for release qualification.

Triggered, serial-enabled acquisition retains all evidence required for
controller/camera alignment, but that multi-million-row analysis no longer
blocks the Stop operation. It remains mandatory before scientific
qualification. Model provenance hashes the
portable manifest, pose sidecar, ONNX source, DeepStream configuration, and
generated engine independently. Runtime preparation additionally binds the
exact localized config/pose schema/class labels/keypoint labels plus the
package ONNX, engine, and selected parser; all seven are rehashed before spawn
and again at structured model-loaded readiness before a triggered `START`.
Run-local effective files are included in qualification source evidence, and a
missing, divergent, or modified effective-runtime identity fails qualification.
Device provenance records the installed
JetPack/L4T/DeepStream/CUDA/cuDNN/TensorRT package versions when available.

Qualification requires a clean commit, complete required component package
versions, and size/SHA-256 identities for the native FLIR and inference plugins.
The `nvidia-jetpack` convenience meta-package is optional when its component
packages provide exact evidence. The durable backend owns preflight, so direct
IPC cannot bypass it; matched hashed status/manifest evidence must prove an
actual GOP-sized H.264 decode through Jetson's explicit `nvv4l2decoder`
path, FFmpeg/FFprobe fallback availability, and disabled automatic AC suspend.
The short hardware-decoder exercise runs before every recording; readiness
evidence is never reused across scientific runs. The exact FFmpeg package
version is part of required platform provenance. The selected task YAML is
copied atomically and boundedly to `config/task.yaml`, with its source path,
run-relative path, size, and hash.

The checked-in `docs/qualification/HARD_POWER_LOSS_PROTOCOL.md` defines the physical
test and retained evidence. The evaluator now treats every nonterminal persisted
run state as a failed qualification gate, so an interrupted acquisition cannot
be mistaken for an incomplete-but-otherwise-valid matrix cell.

Qualification now fails closed for missing/unsupported run-manifest schemas,
dirty or failure-injected/non-production provenance, camera FrameID gaps or
regressions, duplicate/out-of-order inference identities, and orphan inference
rows. Skipped preflight and the qualification-only DeepStream debug profile are
explicit production disqualifiers; the latter has a narrow single-run exception
only for paired overhead measurement and remains forbidden in the production
matrix. The matrix additionally requires one application commit, one complete
device/package/native-plugin identity across every cell, and one hashed
model/engine identity across inference-enabled cells. It binds trigger mode and
edge, controller rate, exposure, recording bitrate, and serial state/port/baud
plus controller protocol at startup, then requires the task snapshot and actual camera
serial/model/firmware/runtime identity to remain identical across the campaign.
A process-owned acquisition lock
prevents two GUI instances from competing for the camera/controller and is
released automatically after a process crash.

1. Turn the pipeline topology and the invariants above into contract tests.
   Assert that the recording queue is non-leaky, all display/inference queues
   are isolated, and every fatal recording condition propagates to run status.
2. Add deterministic failure injection at the source, record queue, encoder,
   muxer, disk, serial controller, and shutdown boundaries.
3. Store a versioned run manifest with Jetson model, Jetson Linux/JetPack,
   kernel, CUDA, TensorRT, DeepStream, GStreamer, Spinnaker, native plugin build
   identity, model/engine hashes, power mode, and application commit.
4. Keep generated TensorRT plans out of the portable source-of-truth model
   package. Build them on an otherwise idle target and reject a plan whose
   recorded TensorRT/device identity does not match the runtime.

   The engine builder now emits schema-3 build identity for TensorRT, CUDA,
   compute capability, Jetson model, and Jetson Linux. Schema-3 model selection
   rejects any runtime mismatch before acquisition. Existing schema-2 packages
   remain readable only as a migration path and must be rebuilt with the
   Project Setup builder to gain the strict identity gate.

   On September 16, 2026 the clean-break Project Setup workflow built the
   project-owned `mousehouse_v2.pt` source into the `Test` project's
   `models/mousehouse` schema-3 package. Independent strict validation matched
   CUDA 13.2, TensorRT 10.16.2.10, compute capability 8.7, device/L4T identity,
   the explicit 1 GiB builder-workspace ceiling, and every path-bound artifact
   digest. A bounded `trtexec` check executed the plan successfully with input
   `1x3x640x640` and output `1x300x63`; its non-truncated execution report is
   itself hashed by the model manifest. A subsequent GUI run loaded that exact
   project package and passed its 2,672-frame capture, MP4-count, alignment,
   feeder-jam, and shutdown checks. The repository-local model package is now a
   legacy ignored artifact and is not a runtime model source.

   The same device also completed an operator-observed bounded direct-source
   FLIR smoke test with
   10/10 complete Mono8 frames, contiguous camera chunk FrameIDs, contiguous
   acquisition stream IDs 0 through 9, valid CRCs, and 1,555,360 valid payload
   bytes per frame. Its raw artifact is not retained in this repository; this
   is a development note, not a GUI recording run or a sustained qualification
   cell.

Exit criterion: the existing validated graph can be reconstructed from tests
and a run can prove its software, model, device, timing, and frame identity.

### Interrupted 88-hour development observation

The operator-reported August 27–31, 2026 bench run demonstrated healthy
camera/encoder endurance
for 88.09 hours: 9,513,447 recording admissions matched 9,513,447 MP4 frames,
the full 134.78 GB MP4 demuxed without error, frame IDs were contiguous, and
recording backlog stayed far below its warning threshold. It is not a validated
scientific run. VS Code died after 45.58 hours and took the GUI-owned serial
ledger with it, while the independently sessionized capture child continued for
another 42.51 hours. The eventual reboot left one final source frame outside
the recording branch and prevented finalization. This is endurance evidence for
the dirty working-tree build only; its raw directory is not retained in this
repository and it is not release qualification evidence. The GUI remains the required operator
interface. The production launcher now starts a detached, Qt-free supervisor
which owns serial control, capture, the acquisition lock, and ordered
finalization, then launches and monitors the GUI. Loss of the GUI or its
exclusive local IPC lease cancels startup or fails an active run through the
same ordered finalizer; acquisition cannot continue headlessly. This boundary
still requires on-device GUI-crash qualification before scientific collection.

## Stage 1: separate responsibilities without changing the graph

Status: repository implementation complete; on-device equivalence remains in
progress. Immutable inference and operator contracts, video probing,
frame audit, recording operators, complete graph construction, capture,
inference, video, and acquisition reconciliation, capture drain, versioned
child/backend events, and pure GUI health/presentation mapping now have
independent modules. Manifest/provenance, preflight execution, process-group
supervision, fail-closed startup orchestration, ordered shutdown coordination,
and bounded post-run finalizer supervision are independent Qt-free services.
`ServiceMakerApp` owns lifecycle
rather than graph construction, and the GUI consumes typed backend phases.
Preview, system meters, finalization presentation, bottle measurements,
dashboard modeling/presentation, session configuration, configuration form and
validation policy, main-view construction/theme, and individual profile dialogs
have been extracted with compatibility façades. `MainWindow` is now an
integration shell whose run orchestration delegates to `RunPresenter` and pure
presentation policy. Capture-output interpretation and the drain coordinator
are independently tested backend services; a human-readable legacy readiness
line can no longer arm the controller without its validated structured event.
Recording liveness and pose CSV persistence are independently tested inference
services.

The operator surface now uses versioned native Qt dock cards instead of a
pixel-tuned central grid. The run-control header remains pinned, the canonical
three-column plus full-width behavior arrangement is always recoverable, and
operator card positions persist independently from run data. Card movement and
floating require an explicit idle-only unlock and are forced locked throughout
startup, recording, and finalization. Every card uses Qt's native hide/show
action: right-click any card title to toggle cards from one unified checklist,
and Reset Layout remains the recovery path if multiple cards are hidden.

Pipeline construction is physically separated into source/recording,
inference/tracking, and preview/output graph modules, with a small mux/resource
orchestrator retaining the golden element order and properties. The GUI consumes
a narrow backend protocol and immutable run snapshots instead of mutating or
reading backend internals. Ordinary child stdout can no longer select an
ambient latest run; only the prepared directory carried by validated structured
lifecycle events is accepted.

The streaming callback audit now hard-caps the pose handoff and dashboard
display history, bounds native metadata inspection, and uses fixed-size
userspace buffering only for sidecars that are read after orderly close. The
record-admission ledger remains line-visible because controller shutdown reads
it before capture closes, and recording telemetry remains line-visible for live
operator health. Abrupt loss of a buffered sidecar tail cannot silently pass:
the nonterminal/unreconciled run fails validation.

Camera runtime identity is accumulated in bounded memory and persisted only
during close, not by atomic JSON replacement on the streaming callback. An
identity change or an unexpected camera count fails closed. The serial reader
also bounds individual lines and its pre-ledger queue, actively closes the port
to unblock shutdown, and promotes reader, port, and ledger-close failures into
run-integrity failures. GUI close requests now pass through the same backend
lifecycle gate as the Stop button: startup is allowed to resolve, capture is
stopped and finalized in order, and the window refuses to disappear when child
exit or finalization cannot be confirmed.

The production process boundary is now separated as well: a Qt-free supervisor
owns the backend and launches the mandatory GUI as its sole authenticated lease
holder. Versioned, bounded Unix-socket messages carry commands and typed events;
backend callbacks only enqueue bounded work and never write the socket. A full
recording-critical queue fails closed, while presentation events may be dropped
with an explicit count. GUI loss is tested before run creation and during
recording/finalization. Startup cancellation and controller `START` are
lease-atomic, and the supervisor remains alive until ordered finalization and
terminal persistence finish.
Run stop is asynchronous at the IPC boundary: the command worker acknowledges
ownership immediately, a non-daemon supervisor worker performs ordered shutdown,
and the GUI waits for terminal lifecycle events while continuing its main-loop
lease. Accelerated blocked-finalizer tests verify stop acknowledgement and
progress snapshots without requiring an hours-long acquisition.

A bounded lease emitted by a Qt-main-loop timer also makes a frozen GUI fail
closed; a proxy background thread cannot renew that lease by itself. The
supervisor validates renewals inline so long startup/finalization commands do
not create false expiry. The acquisition child additionally arms Linux
`PR_SET_PDEATHSIG` before executing DeepStream and verifies its expected parent
PID, preventing a hard supervisor death from leaving the sessionized capture
process running indefinitely.

1. Split the inference runner into pipeline specification, source/recording,
   inference/tracking, preview, telemetry, lifecycle, and artifact-validation
   modules. Keep one lifecycle owner and explicit state transitions.
2. Split the operator backend into immutable run configuration, preflight,
   process supervision, state machine, and finalization services. GUI code
   observes typed state and does not own acquisition lifecycle decisions.
3. Replace unstructured cross-process strings with a versioned event schema;
   retain human-readable logs as a presentation layer.
4. Use bounded queues and constant-memory summaries for long runs. Audit every
   callback/probe so it does bounded work and never performs avoidable blocking
   I/O on a streaming thread.
5. Keep DeepStream Service Maker. DeepStream 9.1 deprecates `pyds` and recommends
   `pyservicemaker`; the Pipeline API is appropriate where this application
   needs exact graph control.

Exit criterion: module boundaries are testable independently, while graph,
artifacts, and on-device frame counts remain identical to the frozen baseline.

## Stage 2: observability and sustained-operation validation

Status: repository tooling complete; empirical qualification remains in
progress. Preflight reports `tegrastats` without the invalid LFB
threshold, rejects automatic AC suspend, and an opt-in NVIDIA latency profile
is available. The capture child now owns a constant-memory `tegrastats`
recorder; during acquisition the GUI follows that CSV instead of launching a
duplicate sampler. `scripts/qualify_run.py` performs bounded-memory evidence
analysis with a versioned measurement-only limits profile. Empirical limits,
instrumentation-overhead measurements, and execution of the sustained
qualification matrix remain open. The versioned 24-cell matrix definition and
bounded evaluator are checked in; they reject run reuse and verify duration,
capture, inference, preview, power-mode, clean Git, production eligibility,
shared commit, and hashed model/engine identity for every inference-enabled
assigned cell.
The evaluator also rejects any cross-cell change in the complete acquisition
protocol or actual camera identity; inference and preview remain deliberate
matrix dimensions rather than acquisition-identity fields.
Each leaky preview queue now has source-identity probes immediately before and
after the queue. Bounded, durable per-camera ledgers reconcile delivered and
intentionally shed preview frames after capture. Their failure blocks
preview-enabled qualification but is explicitly excluded from recording
validity; both probes remain downstream of the recording tee.
Validated limits are schema-checked as a complete finite threshold set, and
qualification fails on invalid/unknown recording telemetry or missing
per-camera recording telemetry coverage.

Limits, matrix, assignment, failure-plan, and debug-threshold inputs must be
stable regular files; reads are size-bounded, strictly typed, duplicate-key
rejecting, and fail closed on unknown fields or case IDs.
Every long-run CSV/JSONL evidence consumer also bounds each physical record,
requires strict UTF-8, and either fails the scientific gate or reports invalid
diagnostics on malformed input. Offline replay indexes frame identity in a
temporary disk-backed database rather than retaining a run-length-sized map in
memory, and rechecks its input identities after decoding before publishing
derived results. Replay uses the decoder EOS audit itself for the exact video
count, avoiding a redundant, fixed-time FFprobe scan of multi-day recordings.
The CLI runs native Service Maker in an isolated worker process: signals request
normal stop/drain first, while an external 45-second supervisor boundary kills
a stuck native teardown and returns failure. Linux parent-death containment
prevents a hard supervisor death from orphaning the native worker. A replay can
never publish success without decoder EOS and the exact ledger count.
System qualification measures per-field and explicit thermal-state coverage so
unknown samples are not treated as safe. Recording metrics reject negative or
non-finite rows, and acquisition health requires camera transport-counter
coverage for every configured stream. Telemetry-recorder loss is persisted as
soon as observed without interrupting the authoritative recording branch, and
it independently fails qualification.

Qualification summaries hash every manifest, status, telemetry, and limits
artifact they consumed. The paired debug comparison rejects stale summaries,
requires the exact debug-only exception, the same validated limits file, and
nonnegative finite NVIDIA latency values. Its checked protocol requires
successfully terminal durable-supervisor runs with the same backend-enforced
qualification case binding and retains both source-evidence reference sets.
Matrix cells require an exact labeled
power mode and one canonical platform/package/native-plugin identity across all
cells, including inference-off cases.

Campaign execution now has a read-only `--next-case` worksheet that exposes the
first unassigned case, exact bound factors, duration, progress, environment,
and terminal launch command without starting acquisition. A strict unapproved
debug-overhead threshold template enumerates all required metrics without
turning measurement defaults into acceptance limits. Completed campaigns can
be inventoried outside their run directories with bounded streaming SHA-256;
the archive verifier rejects missing, extra, symlinked, special, traversing, or
modified copied evidence and never copies or bundles large videos itself.
The recording validator does not accept a duration/header estimate as proof.
The FLIR source writes canonical `frames.csv` rows during acquisition. Routine
shutdown validates the final MP4 sample-size, timing, sample-to-chunk, and
chunk-offset tables against the live manifest and durable final
capture/admission indices. Triggered runs then generate controller/camera
alignment automatically. Shutdown does not reconstruct `frames.csv`, hash or
decode the complete recording, or perform detailed object reconciliation.
The source also writes low-rate camera telemetry, camera integrity events, and
the resolved camera runtime snapshot live, so those diagnostic artifacts do
not require post-run reconstruction. Deferred object statistics are recorded
as unavailable (`null`), never as a misleading measured zero.
Qualification may explicitly request the deeper object or decode checks.

Future development should add richer progress/checkpointing to optional deep
analysis and add a
bounded complete compressed-bitstream scan that does not depend on
`qtdemux`'s per-sample index. None of those items changes the non-leaky
recording path or blocks the metadata/sample-table validation policy above.

Controller alignment now requires the ordered `START_SENT`,
`CAPTURE_STOP_REQUESTED`, `STOP_SENT`, and `CAPTURE_STOP_DONE` markers. Its
trigger epoch starts immediately after `START_SENT` and continues through the
end of the bounded serial ledger: every `CAMERA_HIGH` in that epoch, including
the shutdown tail after `CAPTURE_STOP_REQUESTED`, must map bijectively to one
recorded camera frame. The summary records unmatched epoch and tail counts;
automatic alignment and later qualification both fail closed unless those counts
are zero and the video/frame-ledger count also matches. Qualification binds the
exact alignment-summary bytes it parsed into its source evidence.

1. Add an opt-in debug profile that captures DeepStream frame/component latency
   (`NVDS_ENABLE_LATENCY_MEASUREMENT` and
   `NVDS_ENABLE_COMPONENT_LATENCY_MEASUREMENT`) and Service Maker performance
   data beside existing recording telemetry. Measure its overhead before use
   during scientific runs.

   Initial support is available with
   `SQUEAKVIEW_DEEPSTREAM_DEBUG_PROFILE=1`; it enables both NVIDIA latency
   variables in the capture subprocess and attaches NVIDIA's shipped
   `measure_latency_probe` and `measure_fps_probe` only downstream of the leaky
   inference input. Preflight hashes both bounded regular-file modules into the
   run manifest, and child output is retained in the run-local, 64 MiB-bounded
   `diagnostics/deepstream.log`. When that profile makes
   `NVDS_ENABLE_LATENCY_MEASUREMENT` truthy, the raw FLIR source now calls
   NVIDIA's public `nvds_add_reference_timestamp_meta` immediately after setting
   buffer timestamps, using its real GStreamer element name and acquisition-local
   source sequence. The API returns no status, and NVIDIA's header documents
   decoder names as its standard anchors, so this correct raw-source anchor still
   does not prove that frame-latency records will be nonempty on this graph. It
   marks the run non-production and remains qualification-only until both structured frame
   and component latency plus finite Service Maker FPS evidence is observed
   without log truncation and its overhead is measured. Only
   `scripts/qualify_run.py --allow-debug-profile` may waive that single reason
   for the paired overhead comparison; the sustained production matrix still
   rejects it. The comparison remains incomplete until explicitly approved,
   evidence-derived overhead thresholds are supplied.

Acquisition additionally enforces the same free-space reserve used at startup
through a constant-memory live monitor. A reserve breach or disk-query failure
emits a structured fatal event and enters normal EOS/container draining; it is
not converted into an abrupt process kill. The resolved threshold, check
interval, and fail-closed policy are retained in the run manifest.
2. Capture `tegrastats` CPU, GPU, EMC, RAM, temperatures, throttling, and power
   rails at a bounded interval. Treat LFB as informational: NVIDIA defines its
   largest block as at most 4 MB, so a 16 MB warning threshold is invalid.
3. Benchmark sustained acquisition in the bounded 25 W profile and
   MAXN_SUPER. NVIDIA describes MAXN/MAXN_SUPER as experimental and warns that
   prolonged heavy workloads may throttle. Select the mode that produces stable
   no-drop runs, not merely the highest short benchmark.
4. Disable automatic suspend on acquisition systems and report the policy in
   preflight. Jetson Linux 39.2.1 documents an Orin Nano watchdog-reset risk
   during SC7 suspend/resume.
5. Establish short, one-hour, and full-duration qualification matrices across
   inference on/off, preview on/off, production-supported capture profiles, and
   power mode. The current production scope is explicitly the matrix's single
   1440×1080/30 FPS/one-camera profile. Wider GUI validation ranges are for
   development runs and are not claims of scientific support; any additional
   resolution, rate, pixel format, or camera count requires a new versioned
   capture profile and the complete matrix before production use.

Exit criterion: resource saturation, thermal throttling, and latency regressions
are visible and have defined pass/fail limits derived from validated runs.

## Stage 3: implemented pipeline choices and optional accuracy work

Status: the recording-codec and stream-multiplexer decisions are complete.
Their on-device sustained qualification is covered by the Stage 2 matrix; they
are not competing implementation options that remain to be selected.

1. Preserve CPU x264 recording on Orin Nano unless hardware changes. NVIDIA
   confirms that Orin Nano has no NVENC and documents software encoding as the
   supported path. The system-memory GRAY8 feed avoids an unnecessary
   NVMM-to-CPU round trip. The encoder now explicitly uses one reference frame,
   disables adaptive quantization, B-frames, and lookahead, and retains the
   selected lossy bitrate-controlled scientific format.
2. DeepStream 9.1 Stream multiplexer 2 is now pinned. Because it performs no
   scaling or color conversion, every live and offline input is explicitly
   normalized to NV12 in Jetson surface-array NVMM before the mux. Preflight
   exercises that exact VIC/NVMM path; the physical smoke and sustained matrix
   must still validate FLIR metadata and frame identity through mux and demux.
3. Consider TensorRT precision or model changes only with accuracy validation
   against a fixed scientific dataset. Never reuse JetPack 6/TensorRT 8 plans or
   calibration artifacts without rebuilding and revalidation.
4. Tune tracker and preview accuracy/performance last, independently of the
   recording branch and only against a fixed annotated dataset.

Exit criterion: each optimization demonstrates equal recording integrity and
acceptable scientific accuracy under the full sustained-run matrix.

## Remaining acceptance gates

The repository implementation is not the same as scientific qualification.
The following work intentionally remains open and must not be inferred from a
green unit-test suite:

1. Completed on 2026-09-16 for the clean-break project workflow: a fresh
   project built the schema-3 `mousehouse` package on-device, selected it as the
   project default, and used that exact engine in a successful 2,672-frame GUI
   smoke. Generated engines remain project-owned, device-local artifacts and
   are never portable repository content.
2. Run the remaining one-hour and full-duration on-device matrix with real
   camera/controller hardware, approve evidence-derived limits, and retain the
   resulting qualification summaries. The short recording, feeder-jam, and
   normal shutdown path, relaunch restoration, and second-project isolation have
   passed; safe-bench GUI loss, physical serial fault, and hard-power-loss
   evidence remain.
3. Run a matched DeepStream debug-off/debug-on pair and confirm that NVIDIA
   latency records are actually present before accepting the instrumentation;
   then measure its acquisition overhead with the checked-in comparison tool.
4. Exercise the durable supervisor on-device by freezing and forcibly
   terminating the GUI during startup, recording, and each finalization phase,
   and by terminating the supervisor during capture. Retain evidence that
   startup never arms after lease loss, active acquisition stops, MP4 EOS/drain
   completes when possible, serial and frame ledgers close, the acquisition
   lock releases only after terminal status persistence, and no capture process
   survives headlessly. A hard supervisor death cannot perform ordered
   finalization, so its run must remain visibly nonterminal/failed qualification.
   Use the guarded, dry-run-first procedure in
   [SUPERVISOR_FAILURE_PROTOCOL.md](SUPERVISOR_FAILURE_PROTOCOL.md) for the
   active-capture and individual persisted finalization-stage cases; it records
   and immediately rechecks exact PID/start-time/parent/workload identities and
   never performs broad process-name signaling. Its supervisor action is a
   catchable `SIGTERM` test. An uncatchable supervisor-death test remains
   coupled to the controller watchdog safety gate below.

   Qualification-only bounded barriers now make `pre_capture`,
   `after_spawn_before_ready`, and the capture-reconciliation,
   inference-admission, recording-validation, and streaming-alignment stages
   deterministic. They require the explicit destructive-test gate, mark the run
   non-production, persist their waiting state, respond to cancellation, and
   self-release within 60 seconds. The injection helper can wait for the exact
   barrier while retaining its dry-run and UID/PID/start-time/parent/argv/run
   identity checks.
5. Obtain and version the deployed RP2040 firmware, implement its lease/watchdog,
   and produce durable electrical failsafe evidence. The host side now has an
   explicitly opt-in, production-disqualified experimental v1 state machine:
   nonce-bound negotiation and ACKs, bounded startup/disarm waits, monotonic
   heartbeat renewal from the supervisor, and fatal shutdown after two missed
   acknowledgements. Legacy behavior remains the default. The current repository
   has no firmware package or qualified watchdog, so host parent-death containment
   alone cannot guarantee
   that an independently powered controller stops pulses after Jetson failure.
   [CONTROLLER_WATCHDOG_PROTOCOL.md](CONTROLLER_WATCHDOG_PROTOCOL.md) now defines
   the exact wire/host/electrical contract and opt-in instructions; none of the
   host-only tests count as controller or electrical safety evidence.

Lossless/raw recording and the legacy stream multiplexer are explicitly not
remaining acceptance gates. The production architecture is the current lossy,
bitrate-controlled H.264 recording path and DeepStream 9.1 Streammux 2. Those
choices must pass the sustained matrix above, but no alternative recording
format or mux implementation needs to be developed or compared for this
release. Reversing either decision would require a new scientific requirement,
an isolated implementation, and a separate qualification campaign. Inference
precision, tracker, and preview changes remain deferred until fixed-dataset
accuracy evidence justifies them.

## NVIDIA references

- [JetPack 7.2.1 downloads and supported component versions](https://developer.nvidia.com/embedded/jetpack/downloads)
- [Jetson Linux 39.2.1 release notes and known issues](https://docs.nvidia.com/jetson/archives/r39.2.1/ReleaseNotes/Jetson_Linux_Release_Notes_r39.2.1.pdf)
- [Orin Nano software encoding and libx264 guidance](https://docs.nvidia.com/jetson/archives/r39.2.1/DeveloperGuide/SD/Multimedia/SoftwareEncodeInOrinNano.html)
- [Jetson `tegrastats` field definitions](https://docs.nvidia.com/jetson/archives/r39.2/DeveloperGuide/AT/JetsonLinuxDevelopmentTools/TegrastatsUtility.html)
- [Jetson Orin power and performance guidance](https://docs.nvidia.com/jetson/archives/r39.2/DeveloperGuide/SD/PlatformPowerAndPerformance/JetsonOrinNanoSeriesJetsonOrinNxSeriesAndJetsonAgxOrinSeries.html)
- [DeepStream 9.1 release notes](https://docs.nvidia.com/metropolis/deepstream/dev-guide/text/DS_Release_notes.html)
- [DeepStream 9.1 migration guidance](https://docs.nvidia.com/metropolis/deepstream/dev-guide/text/DS_Migration_guide.html)
- [DeepStream performance troubleshooting](https://docs.nvidia.com/metropolis/deepstream/9.1/text/DS_troubleshooting.html)
- [DeepStream Service Maker overview](https://docs.nvidia.com/metropolis/deepstream/9.1/text/DS_service_maker_intro.html)
- [Service Maker Python advanced features](https://docs.nvidia.com/metropolis/deepstream/dev-guide/text/DS_service_maker_python_advanced_features.html)
- [TensorRT engine compatibility](https://docs.nvidia.com/deeplearning/tensorrt/latest/inference-library/engine-compatibility.html)

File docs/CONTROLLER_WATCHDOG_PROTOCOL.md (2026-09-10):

# RP2040 Controller Watchdog Protocol and Host Contract

Status: **specification only; firmware and hardware qualification are not present in this repository.**

This document defines the controller safety boundary required before triggered
SqueakView acquisition can be called resilient to total Jetson, supervisor, USB,
or host-power failure. The current deployed host protocol is legacy `START,<fps>`
and `STOP`, with `CAMERA_*` telemetry and `ACK_STOP`. It has no negotiated lease.
The Python host therefore must not claim that an independently powered controller
will stop pulses after the Jetson dies.

Normative words **MUST**, **MUST NOT**, **SHOULD**, and **MAY** describe the future
watchdog-capable firmware and its matching host integration.

## Safety invariants

1. Reset, boot, USB disconnect, malformed input, expired lease, and internal
   watchdog reset MUST put the physical camera-trigger output in its inactive
   electrical level before any other application action.
2. The controller MUST boot `DISARMED`. It MUST NOT emit a trigger because a USB
   port opened, a `HELLO` arrived, or a previous session was armed.
3. Only a successfully negotiated, session-bound `ARM` may enter `ARMED`.
4. While `ARMED`, failure to receive a valid heartbeat before the monotonic lease
   deadline MUST synchronously disable the trigger and latch `WATCHDOG_TRIPPED`.
5. `WATCHDOG_TRIPPED` MUST require a new session nonce and new `ARM`; a delayed
   packet from the previous session MUST NOT restart output.
6. `STOP`/`DISARM` MUST disable the trigger first, then emit its acknowledgement.
7. Host logging, GUI state, or USB presence MUST NOT be part of the controller's
   safety action. The RP2040 hardware timer/watchdog owns the deadline.

## Transport and framing

- USB CDC serial, 115200 baud, 8-N-1, newline-delimited ASCII.
- Maximum line length: 512 bytes including arguments but excluding `\n`.
- Commands and event names are uppercase and comma-separated. Fields MUST NOT
  contain commas, newlines, or control characters.
- Integers are unsigned base-10 with no sign. Nonces are 32 lowercase hexadecimal
  characters. Unknown commands receive `ERROR,<nonce>,UNKNOWN_COMMAND` and MUST
  NOT change output state.
- Duplicate commands with the same nonce and sequence number are idempotent.

The host's existing 64 KiB serial input bound remains defense in depth; qualified
firmware is held to the tighter 512-byte bound.

## Version and capability negotiation

The future host opens the port while capture remains unstarted and sends:

```text
HELLO,1,<session_nonce>,<requested_lease_ms>
```

Qualified v1 firmware replies:

```text
CONTROLLER_CAPS,1,<session_nonce>,<firmware_version>,<watchdog_timeout_ms>,lease_watchdog;trigger_low_failsafe;session_nonce;telemetry_v1
```

The reply nonce MUST exactly match the current `HELLO`; this prevents a delayed
capability advertisement from an earlier connection from satisfying negotiation.
`watchdog_timeout_ms` MUST be 100–60000 and MUST be no greater than the requested
lease. The host MUST reject a version other than `1`, a missing required feature,
an out-of-policy timeout, malformed fields, or no response within the negotiated
startup deadline. Rejection occurs before camera/controller `START` and is
production-fatal.

The host now contains an opt-in, unit-tested experimental v1 implementation. It
sends nonce-bound `HELLO`, validates the complete required feature set, waits for
nonce/sequence-bound arm/disarm acknowledgements, and renews the lease from the
Qt-free supervisor. Legacy `START`/`STOP` remains the default. The experimental
path is selected only by launching with
`SQUEAKVIEW_CONTROLLER_PROTOCOL=watchdog_v1_experimental`; its requested lease
may be set with `SQUEAKVIEW_CONTROLLER_WATCHDOG_LEASE_MS` (default 1500). It is
always recorded as `controller_watchdog_unqualified` and is therefore never
production eligible. Do not enable it against existing legacy firmware.

## Arm, heartbeat, and disarm

After DeepStream is ready and all pre-start metadata is durable, the future host
sends:

```text
ARM,1,<session_nonce>,<fps>,<sequence>
ACK_ARM,1,<session_nonce>,<sequence>,<controller_monotonic_us>
HEARTBEAT,1,<session_nonce>,<sequence>,<host_monotonic_ns>
ACK_HEARTBEAT,1,<session_nonce>,<sequence>,<controller_monotonic_us>,<ttl_count>
DISARM,1,<session_nonce>,<sequence>
ACK_DISARM,1,<session_nonce>,<sequence>,<controller_monotonic_us>,<ttl_count>
```

- `fps` MUST be within a firmware-compiled safe range and MUST match the accepted
  experiment rate.
- The first trigger MUST occur only after `ACK_ARM` has been queued for delivery.
- Heartbeat sequence numbers MUST strictly increase. Repeats MAY be acknowledged
  idempotently but MUST NOT extend the lease; older values MUST be ignored.
- The host SHOULD transmit every `watchdog_timeout_ms / 3`, using monotonic time.
  It MUST treat two missed acknowledgements or any write/read error as a fatal run
  fault and begin host-side STOP/finalization.
- The controller MUST renew the lease only after validating version, nonce,
  sequence, and full frame syntax. Arbitrary serial traffic does not renew it.
- `DISARM` and legacy `STOP` MUST both force inactive output. During migration,
  watchdog firmware MAY accept legacy `START,<fps>`, but doing so MUST remain
  production-ineligible because it has no session lease.

## Watchdog telemetry

Every transition is persisted through the existing raw `serial.csv` ledger. New
firmware emits these bounded lines:

```text
CONTROLLER_STATE,1,<nonce>,<DISARMED|ARMED|WATCHDOG_TRIPPED>,<controller_us>,<ttl_count>,<reason>
CONTROLLER_HEALTH,1,<nonce>,<controller_us>,<ttl_count>,<last_heartbeat_sequence>,<lease_remaining_ms>,<reset_cause>
```

`CONTROLLER_HEALTH` SHOULD be emitted once per second while armed and once on
each transition. `reason` and `reset_cause` are enumerated tokens, not free text.
At minimum: `BOOT`, `ARM_COMMAND`, `DISARM_COMMAND`, `LEASE_EXPIRED`,
`USB_DISCONNECT`, `INTERNAL_WATCHDOG`, and `INVALID_COMMAND`.

The experimental host records its protocol, nonce, requested/negotiated timeout,
features, arm state, and final TTL count in the run manifest. Qualification must
extend that evidence to include firmware version,
firmware binary SHA-256, negotiated timeout/features, session nonce, heartbeat
counts, final TTL count, final state, reset cause, and qualification identity.
Raw lines and host receive clocks remain in `serial.csv` for alignment.

## Host integration contract

The production host implementation, once compatible firmware exists and the
experimental implementation has passed bench qualification, MUST:

1. Negotiate before spawning/arming acquisition and reject legacy/no-response
   controllers for watchdog-required triggered runs.
2. Generate a cryptographically random nonce per run and never reuse it.
3. Start heartbeat renewal from the durable Qt-free supervisor, not the GUI and
   not the capture child. GUI loss still initiates normal ordered shutdown; total
   supervisor/Jetson loss is covered by lease expiry.
4. Use a bounded nonblocking heartbeat queue of capacity one. A missed write is a
   fault, never an invitation to accumulate pending heartbeats.
5. Confirm `ACK_ARM` and the first camera TTL before publishing `RECORDING`.
6. On stop: send `DISARM`; confirm inactive state and `ACK_DISARM`; reconcile the
   final TTL count; then drain/close capture, close serial, and validate artifacts.
7. Mark the run failed if negotiation, heartbeat, acknowledgement, telemetry,
   final-state evidence, or TTL reconciliation is absent or inconsistent.

## Fault-injection and bench procedure

Use a logic analyzer or oscilloscope on the actual trigger output and a second
independent clock/reference channel. Do not infer electrical fail-safe timing only
from host logs.

For each supported firmware binary, device revision, cable/power arrangement,
rate, and lease timeout:

1. Verify boot/reset output remains inactive for at least 60 seconds without a
   host.
2. Negotiate and arm; verify frequency, polarity, first-pulse ordering, and
   heartbeat acknowledgements.
3. Stop host heartbeats while leaving USB and both devices powered.
4. Kill the supervisor with `SIGKILL` while leaving the controller powered.
5. Disconnect USB during output-high and output-low phases.
6. Remove Jetson power while keeping the controller independently powered.
7. Inject truncated, oversized, duplicated, reordered, wrong-nonce, wrong-version,
   and high-rate command streams.
8. Reset/brown-out the RP2040 while armed and exercise its internal watchdog.
9. Verify a delayed heartbeat/ARM from the old session cannot restart triggers.
10. Repeat enough trials to cover timing phase and establish a documented upper
    confidence bound, including the maximum pulses after the last valid lease.

Firmware-only injection hooks MUST be compile-time qualification features, visibly
reported in capabilities, and forbidden in production builds. Host serial
`read_error`, `write_error`, and `ledger_write_error` plans test host fail-close
behavior but do not substitute for the electrical tests above.

## Acceptance evidence

A watchdog qualification is complete only when an immutable evidence bundle has:

- firmware source revision, reproducible binary, SHA-256, compiler/SDK versions,
  RP2040 board revision, wiring/polarity, and power topology;
- host commit, JetPack/kernel identity, exact negotiated transcript, and all
  `serial.csv`/run manifests;
- raw logic-analyzer captures with calibrated time base for every fault case;
- measured arm latency, heartbeat jitter, lease-expiry-to-inactive latency, pulse
  width/rate, final TTL count, and pulses after expiry/disconnect/power loss;
- explicit pass criteria: output reaches and remains inactive within the
  negotiated watchdog deadline, **zero new trigger pulses begin after expiry**,
  old-session traffic cannot rearm, and the host run is non-successful;
- repeated-trial counts, failures, equipment calibration, operator/date, and
  independent review sign-off.

Until those artifacts exist, SqueakView
documentation and UI must describe watchdog protection as unqualified/not
available. Successful legacy `START`/`STOP` tests do not close this safety gap.

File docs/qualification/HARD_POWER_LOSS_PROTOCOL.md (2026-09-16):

# Hard-power-loss qualification protocol

This is a destructive bench qualification, not a normal operating procedure.
Use a dedicated test run and storage that contains no irreplaceable data. Do
not substitute `reboot`, `shutdown`, or closing the GUI: those exercise orderly
software paths rather than loss of input power.

## Preconditions

1. Commit the exact candidate build and rebuild the model engine through
   Project Setup to produce its schema-3 manifest. Confirm ordinary short GUI
   runs qualify first.
2. Launch the GUI from a standalone terminal, with the serial controller and
   camera connected exactly as they will be in production.
3. Record the Jetson supply, storage device/filesystem, power mode, model hash,
   application commit, and selected run directory.
4. Use a switched, current-rated bench supply under local operator control.
   Expect filesystem damage; never perform this remotely or during a real
   experiment.

## Procedure

1. Start a triggered GUI run and confirm camera TTLs, recording admissions,
   MP4 growth, and system telemetry for at least five minutes.
2. Without pressing **Stop**, remove DC input power at the bench supply.
3. Restore power, boot normally, and copy the interrupted run directory before
   attempting any recovery or modification.
4. Record filesystem/kernel errors and inspect the copied `run_status.json`,
   ledgers, recording telemetry, and MP4 with the application full-decode
   validator (`ffmpeg -xerror`), not a container-header frame count.
5. Run the read-only-derived qualification report outside the copied run:

   ```bash
   .venv/bin/python scripts/qualify_run.py /path/to/copied-run \
     --output /tmp/power-loss-qualification.json
   ```

6. Confirm that the report is `failed`, including
   `terminal_success_state: false`; an interrupted `recording`, `stopping`, or
   `finalizing` state must never qualify as scientific evidence.
7. Start and cleanly stop a new short GUI run. It must acquire the process lock,
   camera, serial controller, and output storage normally after the crash.

## Acceptance evidence

- The interrupted run cannot qualify or be mislabeled production-complete.
- No frames after the last durable source/admission records are invented.
- Any readable MP4 prefix is treated as salvage only, never as a finalized run.
- The acquisition lock is released by process death and the next clean run
  validates successfully.
- The copied interrupted directory, qualification JSON, console log, kernel
  log excerpt, and next clean-run manifest are retained with the test record.

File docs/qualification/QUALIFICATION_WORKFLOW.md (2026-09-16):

# Sustained qualification workflow

This workflow prepares and evaluates the complete qualification matrix without
silently treating missing hardware, missing evidence, or provisional limits as
a pass. The checked-in matrix currently contains 24 cases. Its nominal capture
time is 136 hours 40 minutes (eight five-minute, eight one-hour, and eight
16-hour runs), before startup, finalization, review, reruns, and storage-copy
time. Plan capacity and operator coverage accordingly.

All `qualification/...` paths below are relative to the active scientific
project, not the application repository. Before running the commands, use the
application root as the working directory and export the project explicitly:

```bash
export SQUEAKVIEW_PROJECT="/absolute/path/to/My Project"
```

## Prepare the checklist

List the canonical case IDs and all required factors without accessing a camera
or controller:

```bash
.venv/bin/python scripts/qualify_matrix.py --list-cases
```

Create a checklist containing every case ID. Existing files are never replaced:

```bash
.venv/bin/python scripts/qualify_matrix.py \
  --init-assignments "$SQUEAKVIEW_PROJECT/qualification/assignments.local.yaml"
```

Each value initially is `null`, which means unassigned. Keep this file for the
entire campaign; it is the durable record of completed and outstanding cells.
Do not commit it when it contains local run paths.

Print the first unassigned case as a read-only worksheet:

```bash
.venv/bin/python scripts/qualify_matrix.py \
  "$SQUEAKVIEW_PROJECT/qualification/assignments.local.yaml" \
  --next-case
```

The JSON output includes progress counts, every bound capture/inference/preview
factor, the power mode, required minimum duration, an explicit environment map,
and a copyable launcher command. It never starts, stops, assigns, or modifies a
run. Set the named power mode separately and verify it with `nvpmodel -q` before
using the command. The generated environment requires
`SQUEAKVIEW_VIDEO_VALIDATION_FULL_DECODE=1`; routine structural validation is
valid for ordinary scientific runs but cannot satisfy the qualification gate.

## Acquire and assign a cell

The production matrix requires the specified FLIR camera for every cell. A
triggered protocol also requires the qualified controller and firmware safety
boundary. Inference-off is a capture test, not a hardware-free simulation. If
the camera or required controller is unavailable, prepare or inspect the
checklist only; leave those cells unassigned. They correctly remain
`incomplete`.

Only capture profiles explicitly listed in the selected versioned matrix are
in production qualification scope. The GUI accepts wider dimensions and frame
rates for development and characterization, but those settings are not
scientifically supported until added to a new matrix version and exercised
through every required cell.

Before each cell:

1. Run `bash scripts/preflight.sh` with the same model, camera, controller, and
   environment that the acquisition will use. Do not use a skipped preflight in
   the production matrix.
2. Select the matrix cell's capture, inference, and preview settings in the GUI.
   For preview-off cells, export `SQUEAKVIEW_DISABLE_PREVIEW=1` before launching;
   remove it for preview-on cells. Select inference on/off explicitly in the GUI.
   Set the named `25W` or `MAXN_SUPER` nvpmodel mode through the device's normal
   provisioning procedure and verify the exact label with `nvpmodel -q`.
3. Launch with `bash squeakview.sh` from a standalone terminal and
   let the requested minimum duration elapse. Wait for terminal finalization;
   never assign an active or partially finalized run.

Bind the launch to the exact canonical case before starting the supervisor:

```bash
export SQUEAKVIEW_QUALIFICATION_CASE_ID='<case-id>'
# Only for a deliberately selected alternate versioned matrix:
# export SQUEAKVIEW_QUALIFICATION_MATRIX='/absolute/path/to/matrix.yaml'
bash squeakview.sh
```

The supervisor-owned backend loads the strict matrix and compares the effective
width, height, FPS, camera count, pixel format, trigger mode/edge, controller
rate, exposure, recording bitrate, serial port/baud/state, inference state,
preview state, and exact current nvpmodel label before creating a run directory
or arming the controller. A mismatch aborts startup. The immutable manifest and
initial run status retain the matrix ID and SHA-256, case ID, and expected factors. Unset
`SQUEAKVIEW_QUALIFICATION_CASE_ID` after the campaign for ordinary unbound runs.

Record the run with the canonical case ID printed by `--list-cases`:

```bash
.venv/bin/python scripts/qualify_matrix.py \
  "$SQUEAKVIEW_PROJECT/qualification/assignments.local.yaml" \
  --assign '<case-id>' '/absolute/path/to/completed/run'
```

The command rejects unknown IDs, missing manifest/status artifacts, and reuse of
one run for two cells. It atomically updates the checklist. Re-running it for
the same case intentionally replaces that case's assignment; the prior run
directory remains untouched.

## Limits and evaluation

`$SQUEAKVIEW_PROJECT/qualification/limits.v1.yaml` is deliberately measurement-only. Evaluating
against it produces `incomplete`, even when capture integrity passes. Use the
short and sustained baseline evidence to create a separately reviewed,
versioned limits file, fill every required finite threshold, and set
`validated: true`. Do not turn the checked-in measurement template into an
approval merely to obtain a passing exit code.

Evaluate at any time to see missing, failed, and completed cells. Give each
campaign report a durable filename instead of relying on the replaceable
default report:

```bash
.venv/bin/python scripts/qualify_matrix.py \
  "$SQUEAKVIEW_PROJECT/qualification/assignments.local.yaml" \
  --limits "$SQUEAKVIEW_PROJECT/qualification/<reviewed-validated-limits>.yaml" \
  --output "$SQUEAKVIEW_PROJECT/qualification/results/<campaign>-matrix-report.json"
```

Exit status is `0` only for a fully passed matrix, `1` for any failed cell, and
`2` for incomplete input or cells. Retain together:

- the exact matrix and validated-limits files;
- the completed assignment checklist;
- the generated matrix report; and
- every assigned immutable run directory and its qualification summary.

The evaluator checks exact factors and power-mode labels, minimum durations,
production/preflight status, clean shared Git provenance, one complete shared
device/package/native-plugin identity, and shared model content identity for
inference-enabled cases. It also requires one canonical acquisition identity
across every assigned cell: the task snapshot hash, all trigger/controller and
recording settings, and the actual camera serial/model/firmware/runtime
configuration. This prevents runs from different experimental protocols or
different camera hardware from being combined into one passing campaign. An
assigned run must also contain an exact backend
startup binding to that matrix document and case; a manually assigned legacy or
unbound run fails the cell. The evaluator does not synthesize evidence for
unavailable hardware or extrapolate short runs into sustained cells.

## Inventory and verify the retained campaign

Create a durable content inventory outside every assigned run directory. This
command never copies, archives, or changes run data:

```bash
.venv/bin/python scripts/archive_qualification_campaign.py \
  --matrix "$SQUEAKVIEW_PROJECT/qualification/matrix.v1.yaml" \
  --assignments "$SQUEAKVIEW_PROJECT/qualification/assignments.local.yaml" \
  --report "$SQUEAKVIEW_PROJECT/qualification/results/<campaign>-matrix-report.json" \
  --limits "$SQUEAKVIEW_PROJECT/qualification/<reviewed-validated-limits>.yaml" \
  --inventory /absolute/archive-staging/<campaign>-inventory.json
```

It rejects incomplete assignments, reused/missing runs, active or nonterminal
status, mismatched report assignments, symlinks, special files, and unbounded
artifact trees. It records streaming SHA-256 and byte-size identities for all
four control documents and every assigned-run file. Copy files to the recorded
`archive_path` values using the site's validated storage procedure, then verify
the exact copied tree without modifying it:

```bash
.venv/bin/python scripts/archive_qualification_campaign.py \
  --verify /absolute/copied-campaign-root \
  --inventory /absolute/archive-staging/<campaign>-inventory.json
```

Verification rejects missing, extra, traversing, symlinked, or content-mismatched
entries. Keep the inventory beside, not inside, the tree it verifies.

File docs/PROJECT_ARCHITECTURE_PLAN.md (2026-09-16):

# SqueakView Project Architecture Plan

## Objective

Separate replaceable SqueakView application code from durable scientific project
data. A normal install, update, rollback, or clean application checkout must be
unable to modify or remove project settings, model packages, profiles,
qualification records, or run outputs.

This is a clean-break architecture for the next `main`. Existing repository-local
runtime data will not be migrated and legacy repository-relative data paths will
not be supported.

## Ownership model

### Application installation

The Git checkout at `~/Documents/SqueakView` is the application installation.
It contains only replaceable software, its local dependency environment, native
build products, and shipped resources:

```text
SqueakView/
├── squeakview/
├── native/
├── scripts/
├── resources/project_template/
├── build_engine/
├── tests/
├── pyproject.toml
└── uv.lock
```

Runtime code may read this tree. Normal application use must not write to it.
Dependency synchronization and native compilation are explicit installation or
development operations, not runtime operations.

### Scientific project

The default project parent is `~/Documents/SqueakView Projects`. Each project is
self-contained:

```text
MouseHouse/
├── squeakview_project.json
├── .squeakview.lock
├── runs/
├── models/
├── model_sources/
├── tasks/
├── profiles/
│   ├── experiments/
│   └── subjects/
└── qualification/
```

Project metadata and managed paths are schema-validated, size-bounded, and
resolved after symlinks. A managed path may not escape the project root.

### User and runtime state

User/device presentation state belongs under the platform configuration/state
directories rather than inside either the application or a project:

```text
~/.config/SqueakView/       recent project and GUI layout
~/.local/state/SqueakView/  launch logs produced before a project opens
$XDG_RUNTIME_DIR/squeakview/ supervisor sockets and hardware lock
```

Run-specific logs and diagnostics remain inside their immutable run directory.

## Non-negotiable invariants

1. Acquisition cannot start without an explicitly validated active project.
2. Normal runtime operation performs no writes beneath the application root.
3. Every run output is created beneath the active project's `runs/` directory.
4. Model packages, task overrides, profiles, and qualification state are owned by
   the active project.
5. Native plugins and shipped default templates are owned by the application.
6. Project files never depend on an absolute application-installation path.
7. Application updates never execute deletion, cleanup, or migration operations
   against a project.
8. One ownership-token lock prevents concurrent writers to a project.
9. One device-runtime lock prevents concurrent camera/controller acquisition,
   including from different projects.
10. Unknown or newer project schemas are rejected without modification.
11. Run manifests record project identity, application version/commit, selected
    configuration hashes, and device/runtime provenance.
12. Scientific capture, serial, validation, and shutdown behavior remain unchanged
    except for receiving explicit project paths.

## Target interfaces

### Path objects

Introduce immutable, Qt-free path objects:

- `AppPaths`: application root, native sources/builds, shipped resources, scripts.
- `ProjectPaths`: project metadata, runs, models, model sources, tasks, profiles,
  and qualification paths.
- `UserPaths`: configuration, persistent state/logs, and runtime paths.
- `RuntimeContext`: validated composition of the three, passed explicitly to
  services that read or write files.

The application root may still be derived from the installed module. Project and
user roots may not be derived from the application root or current directory.

### Project metadata

Initial schema:

```json
{
  "schema_version": 1,
  "project_id": "uuid",
  "name": "MouseHouse",
  "created_at": "RFC-3339 timestamp",
  "default_model": null,
  "default_task": "default.yaml"
}
```

Paths stored in project metadata are project-relative. Project creation is a
staged transaction: populate and validate a temporary sibling, then atomically
rename it into place.

### Startup workflow

1. Launch the project chooser without opening acquisition resources.
2. Resolve an explicit `--project`/`SQUEAKVIEW_PROJECT` selection, or offer the
   project launcher.
3. Create or open and validate the project.
4. Present Project Setup. Any TensorRT construction runs in a separate worker
   which owns the project lock and must exit before startup continues.
5. Select a published default model or explicitly continue without inference.
6. Pass the canonical project root to the durable supervisor, which acquires the
   complete-session project ownership lock.
7. Load project profiles, models, tasks, and run destination.
8. Acquire the device lock only when starting acquisition.

The chooser is shown on every startup with the most recently opened valid
project preselected. Project switching deliberately occurs only in this
pre-supervisor chooser: close SqueakView and relaunch to select another project.
There is no in-process project switch that could cross an acquisition or
finalization boundary.

## Implementation phases

### Current progress

- Phase 0: ownership model and path inventory documented.
- Phase 1: core path types, strict schema-1 metadata, staged non-overwriting
  creation, containment checks, ownership-token locks, and exclusive project
  sessions implemented.
- Phases 2–6: backend, GUI, launcher, preflight, model builder, qualification,
  and analysis entry points now receive explicit application/project/user paths;
  repo-local runtime fallbacks have been removed. Run-manifest schema 3 makes
  application and project identity mandatory. Automated ownership and isolation
  coverage is implemented.
- Phase 7: direct-checkout install/update workflow selected and documented;
  privileged device provisioning is separate from unprivileged dependency and
  native-build updates. First-time setup creates the default project parent only
  when absent and never changes an existing one. A two-application-root
  update/rollback test verifies that reopening a populated project leaves its
  complete file snapshot unchanged.
- Phase 8: the complete automated suite passes, including a representative
  create/profile/run workflow with the simulated application tree read-only.
  On 2026-09-16 a fresh project built and validated its project-owned YOLO26
  TensorRT package, then completed a triggered inference-enabled hardware smoke
  with 2,672 source, recording-admission, frame-manifest, and MP4 samples; zero
  frame gaps, incomplete frames, CRC failures, or recording evictions; validated
  controller/camera alignment; successful feeder-jam clear acknowledgement; and
  clean bounded finalization. A subsequent clean relaunch preselected the same
  project and restored its project-owned `mousehouse` default model, `DID`
  experiment, and `TEST` subject. A separately created `Isolation_Test` project
  received independent shipped sources/templates and a unique project ID while
  containing no models, profiles, or runs; the original project's model,
  profiles, and run remained intact. The remaining gates are explicitly divided
  below between repository automation and physical operator qualification.

### Phase 0 — Safety contract and inventory

- Add this architecture document and a machine-readable write-ownership test
  matrix.
- Inventory every existing repository-relative read and write.
- Classify each path as application, project, user-state, or runtime owned.
- Add regression tests around the current run/profile/model behavior before
  changing ownership.

Exit criterion: every mutable path has one declared future owner.

### Phase 1 — Project and path foundation

- Add strict `AppPaths`, `ProjectPaths`, `UserPaths`, and `RuntimeContext` types.
- Add schema-1 project metadata parsing, validation, and transactional creation.
- Add containment and symlink-escape checks.
- Add ownership-token project locking and device-runtime locking.
- Remove import-time directory creation from shared modules.

Exit criterion: temporary projects can be created, opened, locked, and rejected
safely in Qt-free tests.

### Phase 2 — Route backend persistence

- Inject project paths into run context, backend manager, manifests, storage
  checks, qualification services, and post-run tools.
- Move the acquisition lock from repository-local runs state to the runtime lock.
- Record project identity in each run manifest.
- Make subprocess commands receive canonical project/application roots explicitly.

Exit criterion: backend integration tests create all mutable outputs beneath a
temporary project while the simulated application root is read-only.

### Phase 3 — Route operator configuration

- Bind `ProfileStore`, model catalog, task selection, configuration dialogs, Open
  Run Folder, and disk meters to the active project.
- Store GUI layout and recent-project selection in user configuration.
- Remove workspace-anchor path remapping and legacy repository-local defaults.

Exit criterion: two test projects retain independent profiles, tasks, models, and
runs with no cross-project path leakage.

### Phase 4 — Project launcher and lifecycle

- Add Create Project and Open Project startup UI.
- Show the active project in the operator interface.
- Make project switching a close-and-relaunch operation through the mandatory
  pre-supervisor chooser; never switch an active backend's ownership roots.
- Provide clear handling for missing, locked, malformed, and unsupported projects.

Exit criterion: GUI tests cover create/open/reopen, launch-time switching,
locking, and error workflows.

### Phase 5 — Launcher, preflight, and model builder

- Update `squeakview.sh` to place launch logs in user state and pass an explicit
  project selection.
- Split one-time Jetson provisioning from unprivileged application installation.
- Make preflight distinguish application-native assets from project assets.
- Provide a pre-acquisition Project Setup screen which launches an isolated
  worker to consume project model sources and publish validated packages into
  that explicit project before the supervisor starts.
- Copy shipped defaults into new projects rather than editing them in place.

Exit criterion: a fresh project can rebuild a model and pass preflight without
writing to the application tree.

### Phase 6 — Remove legacy architecture

- Remove `SQUEAKVIEW_WORKSPACE`/`PRODUCT_WORKSPACE` as data-root concepts.
- Remove repository-local fallbacks for runs, models, profiles, tasks, and logs.
- Remove workspace-anchor remapping and all compatibility-only tests/docs.
- Ensure repository-local mutable directories are absent from a fresh checkout.

Exit criterion: starting without a project produces a clear launcher/error and
cannot silently recreate legacy directories.

### Phase 7 — Install/update workflow

- Keep the Git checkout at `~/Documents/SqueakView` as the application
  installation; do not copy releases into a second installation tree.
- Update in place with a fast-forward Git pull, `uv sync`, an unprivileged native
  rebuild, and the automated suite before scientific use.
- Roll back code by selecting a known-good commit or tag in the checkout, then
  repeat dependency synchronization, native compilation, and verification.
- Explicitly prohibit project paths as update/cleanup targets.

Exit criterion: updating or rolling back the checkout does not change a
project-tree hash, and normal runtime operation does not write to the checkout.

### Phase 8 — Qualification and handoff

- Run the entire automated suite.
- Test with the application tree read-only.
- Create a fresh MouseHouse project and rebuild its model package.
- Perform short start/stop, feeder-jam, GUI-loss, and validation tests.
- Perform an overnight scientific run only after the short matrix passes.
- Update the README and operator/install documentation for the new workflow.

Exit criterion: all output is project/user/runtime owned, no frames are lost, the
run finalizes correctly, and an application update/rollback leaves the project
unchanged.

### Phase 8 responsibility split

Codex/repository automation must complete without operator assistance:

- the full Python suite and diff/format checks;
- project creation, schema, containment, symlink-escape, and ownership tests;
- simulated read-only application-tree and two-application-root update/rollback
  tests;
- model-builder transaction, cancellation, worker-crash, and project-path tests;
- simulated GUI/supervisor IPC, lease-loss, startup cancellation, finalization,
  and failure-injection tests that do not signal live acquisition hardware;
- documentation and machine-readable ownership audit before commit.

The operator remains responsible only for evidence that inherently requires the
physical system:

- exercising a real camera/controller GUI-loss run on a safe bench;
- serial disconnect, hard-power-loss, and controller electrical-failsafe tests;
- one-hour and full-duration recordings with retained qualification evidence.

The post-reboot RP2040 USB enumeration issue is currently documented but
deferred. Kernel evidence shows that the controller is absent from the USB tree
until a physical reconnect; it is not treated as a completed SqueakView fix.

## User-input gates

Implementation should continue autonomously except at these product decisions:

1. Confirm the visible default project-parent name/location if it should differ
   from `~/Documents/SqueakView Projects`.
2. Resolved: always show the project launcher and preselect the most recently
   opened valid project.
3. Resolved: copy MouseHouse v2 and stock YOLO pose source packages into every
   new project's `model_sources/`; additional sources are project-owned.
4. Resolved: the Git checkout at `~/Documents/SqueakView` is the installation;
   projects default to the sibling `~/Documents/SqueakView Projects` tree and no
   second versioned-install tree is used.
5. Perform physical camera/controller tests and confirm observed GUI behavior at
   the Phase 8 hardware gates.

No existing runtime data will be copied, moved, renamed, or deleted as part of
this plan.

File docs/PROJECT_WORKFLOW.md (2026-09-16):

# SqueakView Project Workflow

The Git checkout is the SqueakView application installation. Scientific projects
are separate sibling directories, so pulling, rebuilding, or rolling back code
does not modify project data. There is no legacy-data migration in this
clean-break release.

## Application checkout and updates

The intended default layout is:

```text
~/Documents/
├── SqueakView/           Git-managed application checkout
└── SqueakView Projects/  Durable scientific projects
```

Clone and prepare the application from `~/Documents`:

```bash
cd "$HOME/Documents"
git clone https://github.com/dlhagger/SqueakView.git
cd SqueakView
uv venv --python 3.12 --system-site-packages
uv sync
bash scripts/setup_jetson.sh
```

`setup_jetson.sh` is the one-time privileged device provisioning step. It creates
`~/Documents/SqueakView Projects` with private user permissions when absent and
leaves it completely unchanged when it already exists. Reboot after setup adds
the operator to `dialout`. Even when setup itself is invoked through `sudo`, its
native compilation runs as the desktop user so it cannot leave root-owned build
artifacts in the Git checkout. For routine application updates, first finish
any active acquisition and close SqueakView, then run:

```bash
cd "$HOME/Documents/SqueakView"
git pull --ff-only
uv sync
bash scripts/build_native.sh
.venv/bin/python -m pytest -q
bash squeakview.sh
```

Routine code updates do not require a reboot. A rollback selects a known-good
Git commit or tag in the same checkout and then repeats `uv sync`, the native
build, and the tests. Update and cleanup commands must never target
`~/Documents/SqueakView Projects`; `.venv/` and native build outputs in the
checkout are replaceable application artifacts, while everything under the
projects directory is durable data.

## Launch and project selection

Start SqueakView from the application checkout:

```bash
bash squeakview.sh
```

The project chooser appears on every launch. The most recently opened valid
project is selected by default, but SqueakView does not open it until the
operator confirms. Choose **Open Other…** for an existing project or **Create
Project…** for a new one. The default parent is:

```text
~/Documents/SqueakView Projects/
```

First launch also creates this parent when absent, so pulling the application
onto an already-provisioned Jetson does not require rerunning system setup. An
existing parent and everything below it are left unchanged.

After selection, Project Setup appears before the acquisition supervisor. It
can build a project source, select an existing published package as the default,
or continue explicitly without inference. Returning from Project Setup goes back
to the chooser. A successful build worker must exit before the recording GUI can
start.

An explicit project path is available for controlled development and scripted
launches:

```bash
bash squeakview.sh "/absolute/path/to/My Project"
```

An open project holds an ownership lock for the complete supervisor session.
The camera/controller acquisition lock is device-wide, so two projects cannot
acquire the hardware concurrently.

## New-project contents

Project creation is staged and then published with one same-filesystem rename;
an existing destination is never replaced. Each new project contains:

```text
My Project/
├── squeakview_project.json
├── .squeakview.lock
├── model_sources/
│   ├── mousehouse_v2/
│   │   ├── mousehouse_v2.pt
│   │   └── mousehouse_v2.yaml
│   └── stock_yolo26_pose/
│       ├── yolo26n-pose.pt
│       └── coco-pose.yaml
├── models/
├── tasks/default.yaml
├── profiles/
│   ├── experiments/
│   └── subjects/
├── qualification/
└── runs/
```

`.squeakview.lock` is a small ownership-token file guarded by the operating
system for the lifetime of an open supervisor session. It prevents two app
instances from writing the same project; a stale unlocked file is harmless.

The two model-source packages are independent project-owned copies. The
application never edits them. They are source checkpoints, not deployable
TensorRT packages; build a device-local package before selecting inference in
the GUI. Users may add other checkpoint/YAML pairs under `model_sources/`.

## Build the MouseHouse v2 package

Launch SqueakView normally and select the project. Before experiments and
subjects are presented, Project Setup displays its model sources. MouseHouse v2
is preselected for a new project; press **Build Model**.

The TensorRT build runs in an isolated process, publishes
`models/mousehouse_v2/` transactionally, selects it as the project default, and
exits before the acquisition supervisor starts. The setup UI never imports the
CUDA build stack, so no manual restart is required. See
[the builder guide](../build_engine/README.md) for the package contract and
diagnostic command.

## Path ownership

- Application: Python code, native plugins, scripts, builder service, and immutable
  new-project templates.
- Project: runs, model sources, generated model packages, tasks, experiment and
  subject profiles, and qualification state.
- User state: recent-project catalog, GUI layout, and pre-project launch logs
  under `~/.config/SqueakView/` and `~/.local/state/SqueakView/`.
- Runtime: supervisor sockets and the device acquisition lock under
  `$XDG_RUNTIME_DIR/squeakview/`.

Run manifests record the canonical project identity and selected project-owned
configuration. Clean-break run-manifest schema 3 distinguishes the replaceable
application root from the durable project root, and qualification rejects a
missing or invalid project identity. Stored profile paths are project-relative
so moving a complete project does not bind it to an application checkout.

## Short on-device acceptance pass

Do this before an overnight or weekend acquisition:

1. Launch with no path. Confirm the chooser appears and preselects the last
   project without opening it automatically.
2. Create a disposable project. Confirm both model-source directories, the
   default task, and all empty project-owned directories listed above exist.
3. Build MouseHouse v2 in Project Setup. Confirm the worker reports that GPU
   resources were released and the package is selected as the project default.
4. Create one experiment and subject, close SqueakView normally, relaunch, and
   verify the chooser and project-local profiles restore correctly.
5. Confirm the Jetson reports NTP synchronization. With the PCF8523-equipped
   controller idle, run clock preflight and confirm seven samples pass the
   ±1.5-second gate. If correction is deliberately authorized, confirm one
   `SET_RTC` acknowledgement is followed by a new seven-sample passing burst and
   inspect `diagnostics/clock_validation.json`. Never attach a DS3231 alongside
   the PCF8523 because both occupy fixed I²C address `0x68`.
6. Run a two-minute triggered recording with inference and preview enabled.
   Confirm the header frame count advances, recording gaps stay at zero, serial
   events remain live, and the project `runs/` directory receives the run.
7. Stop normally. Wait for finalization and confirm `run_status.json` is
   terminal, `run_manifest.json` identifies the project, `raw.mp4` plays, and
   the recording/camera/controller counts pass.
8. On a safe bench setup, trigger a feeder jam. Confirm the persistent warning,
   disabled feeding, exact `CLEAR_JAM` acknowledgement behavior, and successful
   later shutdown.
9. In a separate disposable run, close the GUI during acquisition. Confirm the
   supervisor stops acquisition and produces a failed, terminal run rather than
   continuing headlessly.
10. Open a second project and verify the first project's profiles, models, and
   runs are not offered as the second project's assets.

Keep the short-run directories as acceptance evidence until their manifests and
logs have been reviewed. Only then begin the long-duration qualification run.

### Current acceptance evidence

On 2026-09-16 the `Test` project completed the model-build and primary short-run
gates on the Orin Nano Super. The isolated worker built a project-owned YOLO26
FP16 TensorRT package with a 1 GiB workspace ceiling, passed ONNX and TensorRT
execution validation, published it beneath `Test/models/mousehouse/`, and set it
as the project default. The subsequent triggered inference run recorded 2,672 of
2,672 source frames with zero gaps, incomplete frames, CRC failures, or recording
evictions. MP4 sample counting, controller/camera alignment, bottle persistence,
feeder-jam clear acknowledgement, shutdown, and finalization all passed.
The next launch preselected `Test`; Project Setup recognized `mousehouse` as the
project default without rebuilding; and the `DID` experiment and `TEST` subject
were restored. A new `Isolation_Test` project then received its own unique ID,
both shipped model sources, task, and qualification templates while correctly
starting with no published models, profiles, or runs. The original `Test`
project remained intact and both projects were independently recorded in the
recent-project catalog.

This evidence validates the core project/model/capture route but does not replace
the remaining operator gates: safe-bench GUI-loss behavior and the one-hour and
full-duration runs. Run those from the final clean commit so their manifests
identify the release candidate rather than a dirty development tree.

## Failure behavior

A missing, malformed, unsupported, or locked project is rejected before the GUI
acquires hardware. A reconnect does not rewrite project metadata. If project
creation fails, its unpublished staging directory is removed and the requested
destination remains absent; existing destinations are never cleaned or reused.

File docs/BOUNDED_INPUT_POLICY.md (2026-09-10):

# Bounded Configuration and Metadata Input Policy

SqueakView treats configuration and run metadata as scientific control inputs,
not as arbitrary files. Small documents are read through
`squeakview.common.bounded_input`: the reader opens a regular file, checks its
size before allocation, reads exactly that size, rejects growth or identity
change during the read, and decodes strict UTF-8. JSON objects reject duplicate
keys at every nesting level. Safe YAML mappings use the same stable read and
duplicate-key policy.

Current limits are deliberately much larger than valid repository documents:

| Input | Limit |
|---|---:|
| Failure plans | 64 KiB |
| Latest-run marker | 4 KiB |
| DeepStream inference config | 1 MiB |
| Class/keypoint labels | 1 MiB |
| Task config and snapshotted task config | 1 MiB |
| Operator experiment/subject profile | 1 MiB each, 1,024 files per type |
| Qualification limits, matrix, and assignments | 1 MiB each |
| Pose schema/model metadata | 4 MiB |
| Run status, manifest, and derived JSON metadata | 16 MiB |

Malformed, oversized, duplicate-key, non-regular, changing, or invalid-UTF-8
control documents fail closed before acquisition when they affect startup.
Inference repeats scalar checks, including finite exposure/gain and exact gain
automatic-mode semantics. Qualification and debug comparison use required
strict reads. Matrix reporting intentionally converts invalid per-run metadata
to an empty bounded snapshot so it can report a failed cell rather than aborting
the entire matrix. GUI profile listing likewise skips individual invalid files,
but its enumeration and per-file allocation remain bounded. Profile writes and
localized runtime configs use crash-resistant atomic replacement. Existing
metadata cannot be updated when its current content fails strict validation,
and JSON writers reject NaN and Infinity.

## Intentional streaming and pseudo-file exceptions

The following are not whole-file configuration reads and must not be converted
to the small-document helper:

- capture JSONL and recording-admission CSV use strict UTF-8, duplicate-safe
  parsing with a 64 KiB per-record limit; other frame/serial/telemetry CSV and
  DeepStream latency logs are processed incrementally or through bounded tail
  windows;
- video/model hashing reads fixed chunks and verifies stable identity/size;
- model artifacts and recordings are large binary inputs with their own bounded
  streaming or subprocess validation;
- `/proc`, `/sys`, `/etc/nv_tegra_release`, and device-tree scalar identity
  fields are kernel/platform pseudo-files read as small best-effort context;
- supervisor IPC and child-event JSON are already bounded by their framing or
  line-buffer limits before JSON decoding;
- offline replay reads `frames.csv` through 64 KiB-bounded strict UTF-8 records
  into a temporary disk-backed SQLite ordinal index. Full-duration replay lookup
  therefore remains bounded in memory without weakening source-frame identity.

Callers that make scientific acceptance or lifecycle decisions must use strict
read APIs and propagate failure. The tolerant `run_context.read_json` function
is retained only for presentation, optional progress, initial document
creation, and complete matrix failure reporting; it is still bounded and
duplicate-safe, returning an empty snapshot for invalid input.

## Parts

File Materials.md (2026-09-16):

# MouseHouse and SqueakView Bill of Materials

This bill of materials lists the components used to build the MouseHouse behavioral platform and SqueakView acquisition system described in the manuscript.

Prices and availability may change over time. Equivalent substitutions may be possible but have not necessarily been validated with the published configuration.

## System scope

The validated build includes:

- a 3D-printed MouseHouse enclosure and integrated camera mount;
- a FLIR Blackfly S monochrome machine-vision camera;
- infrared illumination mounted inside the chamber lid;
- a Jetson Orin Nano Super Developer Kit for edge-compute deployment;
- an RP2040-based controller and local event logger;
- optional capacitive-touch lickometer hardware.

---

## A. Edge-compute hardware

| Component | Part used in validated build | Supplier | Qty per station | Approx. unit price | Notes |
|---|---|---|---:|---:|---|
| Edge computer | NVIDIA Jetson Orin Nano Super Developer Kit | NVIDIA Marketplace / authorized distributor | 1 | $249.00 | Runs JetPack, DeepStream, TensorRT, SqueakView, and the operator GUI |
| Edge-compute storage | User-supplied microSD card or NVMe SSD | User-selected | 1 | User-selected | Select capacity based on operating-system and video-recording needs |
| Ethernet cable | Cat5e or Cat6 cable | Multiple suppliers | 1 | User-selected | Recommended for SSH, file transfer, and remote management |

### Storage note

SqueakView does not require a specific storage brand or model. Users may select a compatible microSD card or NVMe SSD based on recording duration, desired storage capacity, and local purchasing preferences.

---

## B. Camera, optics, and acquisition hardware

| Component | Part used in validated build | Supplier | Qty per station | Approx. unit price | Notes |
|---|---|---|---:|---:|---|
| Machine-vision camera | BFS-U3-16S2M-CS USB 3.1 Blackfly® S Monochrome Camera — Stock #11-507 | Edmund Optics / Teledyne FLIR | 1 | $371.00 | 1.6 MP monochrome global-shutter USB3 camera used with the SqueakView acquisition pipeline |
| USB3 camera cable | Type-A to Micro-B USB 3.1 Locking Cable, 3 m — Stock #86-770 | Edmund Optics / Teledyne FLIR | 1 | $25.00 | Locking USB3 cable used for camera data acquisition |
| Camera GPIO cable | Blackfly® 6-pin GPIO Hirose Connector, 1 m Cable — Stock #88-064 | Edmund Optics | 1 | $38.00 | Used for GPIO, trigger, and synchronization connections |
| C-mount spacer | 5 mm Spacer to Convert CS-Mount Cameras to C-Mount | Edmund Optics | 1 | Confirm current price | Required because the selected camera uses a CS mount and the lens uses a C-mount flange distance |
| Camera lens | 4 mm UC Series Fixed Focal Length Lens | Edmund Optics | 1 | Confirm current price | Fixed focal-length machine-vision lens |
| Lens filter adapter | Filter Adapter M62 × 0.75 from M40 × 0.5 Female | Edmund Optics | 1 | $40.50 | Connects the M62 machine-vision filter to the lens |
| Infrared filter | IR (UV/VIS Cut) M62.0 × 0.75 High Performance Machine Vision Filter — Stock #89-842 | Edmund Optics | 1 | $439.00 | Passes infrared illumination while suppressing visible-light contamination |

---

## C. MouseHouse enclosure, camera mounting, and illumination

The MouseHouse chamber enclosure, lid, and camera mount are 3D printed using the CAD files provided in this repository.

The camera mount is integrated into the printed enclosure design, so no separate commercial camera-mounting hardware is required.

The infrared LED strip is cut to the length required for the chamber geometry and adhered directly to the inside surface of the printed lid using its integrated adhesive backing.

| Component | Part used in validated build | Supplier | Qty per station | Approx. unit price | Notes |
|---|---|---|---:|---:|---|
| MouseHouse enclosure | 3D-printed chamber components from repository CAD files | Lab-fabricated | 1 set | User-selected | Includes chamber body and lid |
| Camera mount | 3D-printed camera mount from repository CAD files | Lab-fabricated | 1 | User-selected | Integrated into the MouseHouse enclosure design |
| 3D-printing material | Filament compatible with repository CAD files | User-selected | As needed | User-selected | Record filament type and print settings used locally |
| Infrared illumination | Infrared 850 nm IR LED Strip Light | Waveform Lighting | Cut to fit chamber lid | $55.00 per 1 m or $195.00 per 5 m | Cut to size and adhered to the inner lid surface |
| LED-strip wiring | Header connection and wiring used in validated build | Lab-assembled | 1 set | User-selected | Connects the LED strip to the controller assembly |
| Assembly hardware | Screws, inserts, and connectors required by repository CAD design | Multiple suppliers | 1 set | User-selected | Add sizes and quantities if not obvious from the CAD files |

---

## D. Controller and sensor-logging hardware

| Component | Part used in validated build | Supplier | Qty per station | Approx. unit price | Notes |
|---|---|---|---:|---:|---|
| Microcontroller and logger | Adafruit Feather RP2040 Adalogger — 8 MB Flash with microSD Card, Product ID 5980 | Adafruit | 1 | $14.95 | Core RP2040 controller with removable-storage logging |
| Capacitive-touch controller | Adafruit 12-Key Capacitive Touch Sensor Breakout — MPR121, Product ID 1982 | Adafruit | 1 | $7.95 | Supports capacitive-touch lick detection |
| I²C cable | STEMMA QT / Qwiic JST SH 4-Pin Cable — 50 mm, Product ID 4399 | Adafruit | 1 | $0.95 | Connects STEMMA QT / Qwiic-compatible modules |
| Real-time clock | PCF8523 real-time clock module | Adafruit or equivalent | 1 | Confirm current price | Sole battery-backed controller RTC; do not attach a DS3231 concurrently because both use fixed I²C address `0x68` |
| RTC backup battery | CR1220 coin cell | Adafruit or equivalent | 1 | User-selected | Required for battery-backed RTC operation |
| Controller microSD card | Compatible microSD card | Multiple suppliers | 1 | User-selected | Stores local controller event logs |
| Feather USB data cable | USB data cable compatible with Feather RP2040 Adalogger | Multiple suppliers | 1 | User-selected | Used for programming, power, and serial communication |
| Controller enclosure | Printed or fabricated electronics enclosure | Lab-fabricated | 1 | User-selected | Protects the controller assembly |

---

## E. Optional lickometer module

The capacitive-touch controller can be used to support lickometer-style behavioral measurements. Physical fluid-delivery components may be selected based on the experimental design.

| Component | Part used in validated build | Supplier | Qty per station | Approx. unit price | Notes |
|---|---|---|---:|---:|---|
| Stainless-steel lick spout | Lab-specific | Multiple suppliers | As needed | User-selected | Connected to an MPR121 touch channel |
| Coaxial cable | Lab-specific | Multiple suppliers | As needed | User-selected | Routes electrode and ground connections |
| Ground connection hardware | Wire and connector hardware | Multiple suppliers | As needed | User-selected | Supports stable capacitive sensing |
| Drinking bottle or reservoir | Lab-specific | Multiple suppliers | As needed | User-selected | Holds fluid |
| Tubing | Lab-specific | Multiple suppliers | As needed | User-selected | Connects reservoir and spout |

---

## F. Software dependencies

The following software is required but does not add direct hardware cost.

| Software | Required for |
|---|---|
| NVIDIA JetPack | Jetson operating system and CUDA stack |
| NVIDIA DeepStream SDK | Real-time video inference |
| Teledyne FLIR Spinnaker SDK | Blackfly S camera access |
| SqueakView repository | Acquisition, recording, operator GUI, and inference |
| MouseHouse controller firmware | RP2040-based controller and sensor logging |
| SqueakPose Studio | Pose-model training and export |

---

## G. Approximate subtotal for known-price core components

The following subtotal includes only components with prices currently specified in this document.

| Component | Approx. unit price |
|---|---:|
| NVIDIA Jetson Orin Nano Super Developer Kit | $249.00 |
| FLIR Blackfly S camera | $371.00 |
| USB3 locking cable | $25.00 |
| Camera GPIO cable | $38.00 |
| Lens filter adapter | $40.50 |
| IR-pass filter | $439.00 |
| Feather RP2040 Adalogger | $14.95 |
| MPR121 capacitive-touch controller | $7.95 |
| STEMMA QT cable | $0.95 |
| 1 m IR LED strip | $55.00 |
| **Known-price subtotal** | **$1,241.35** |

This subtotal does not include the camera lens, C-mount spacer, RTC FeatherWing, storage media, printing materials, wiring, fasteners, controller enclosure, optional lickometer hardware, or local fabrication costs.

---

## H. Substitution and reproducibility notes

- The listed camera, optics, and controller components correspond to the validated MouseHouse and SqueakView build.
- Equivalent substitutions may work but have not necessarily been tested with the published configuration.
- Storage capacity is user-selected.
- The IR LED strip is cut to match the chamber geometry.
- The enclosure and camera mount are fabricated from the repository CAD files.
- Experiment-specific lickometer and fluid-delivery hardware may be adapted to local needs.

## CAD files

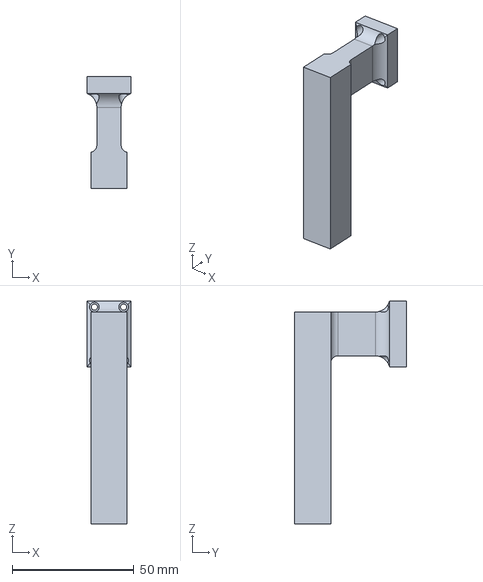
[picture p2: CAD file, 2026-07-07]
MouseHouse CAD files/FLIR_Camera_Top_Mount.step
18.0 x 46.0 x 91.5 mm

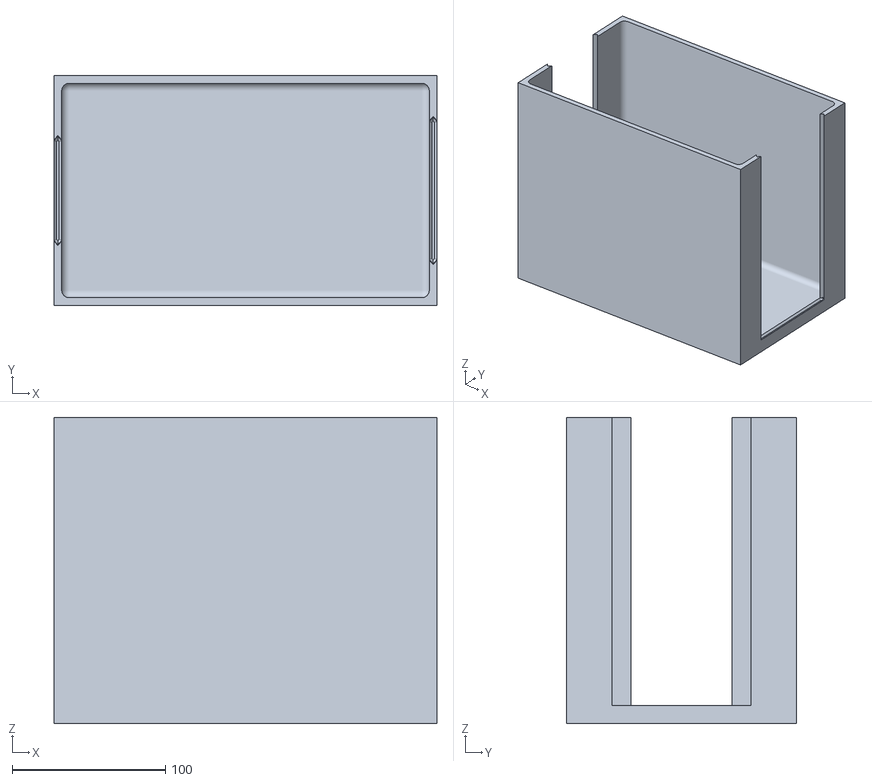
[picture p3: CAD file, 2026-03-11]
MouseHouse CAD files/Box.stl
250.0 x 150.0 x 200.0

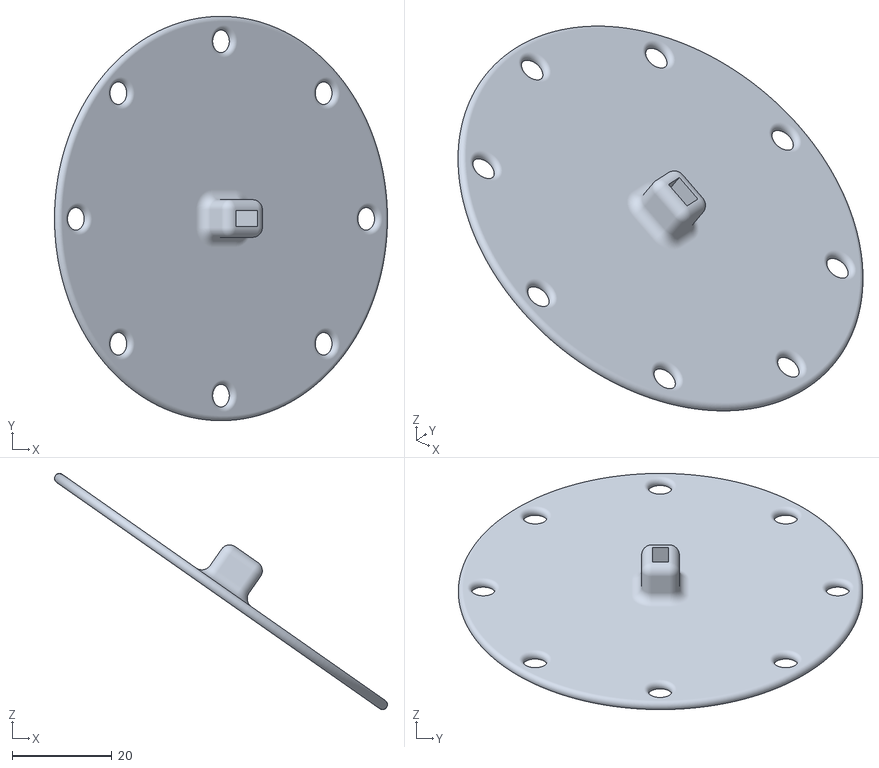
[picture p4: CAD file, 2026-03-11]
MouseHouse CAD files/Disk.stl
66.7 x 81.0 x 47.3

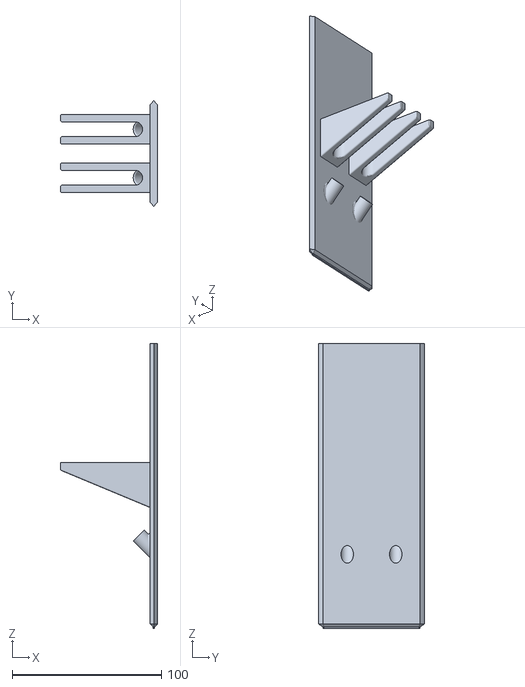
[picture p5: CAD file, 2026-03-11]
MouseHouse CAD files/Lickometer_Plate.stl
65.0 x 71.0 x 191.0

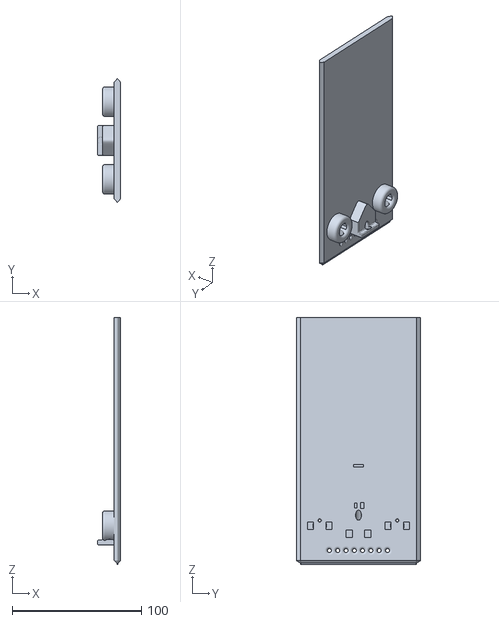
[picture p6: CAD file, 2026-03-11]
MouseHouse CAD files/FED_Plate.stl
18.0 x 96.0 x 191.0

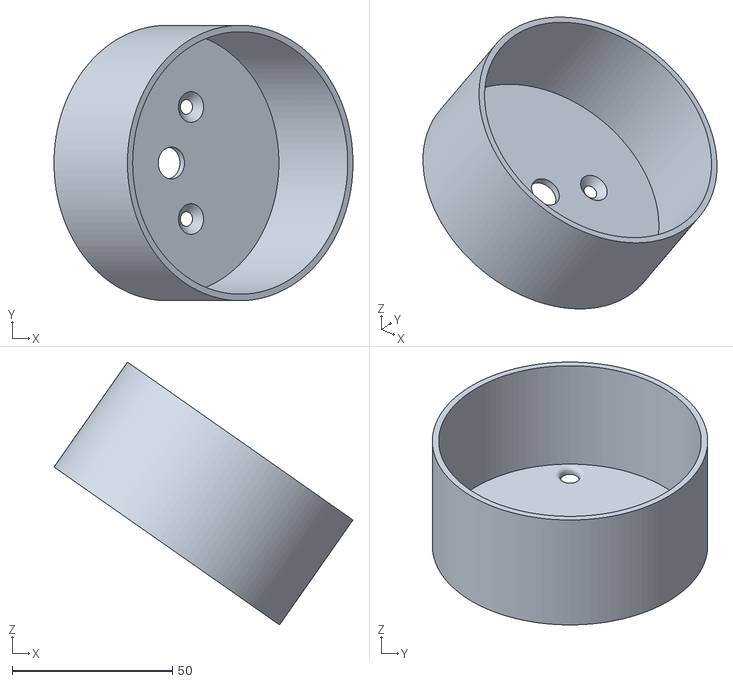
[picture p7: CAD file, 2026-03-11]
MouseHouse CAD files/Hopper_Body.stl
93.4 x 86.0 x 82.1

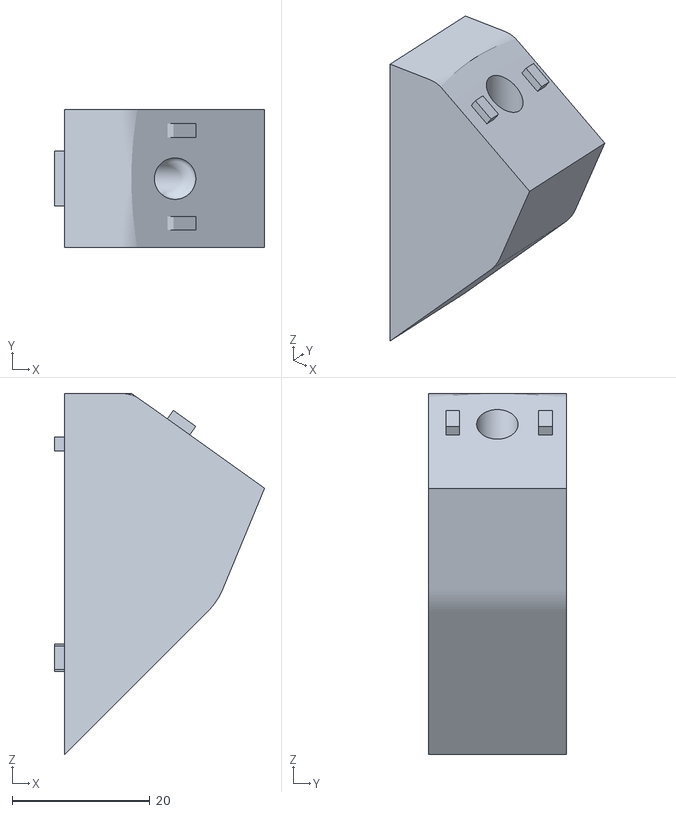
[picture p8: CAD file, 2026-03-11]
MouseHouse CAD files/Hopper_Base.stl
30.5 x 20.0 x 52.3

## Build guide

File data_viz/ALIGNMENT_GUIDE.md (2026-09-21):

# Aligning Protocol-v2 SqueakView Outputs

This guide describes how to construct an analysis timeline from a finalized
SqueakView protocol-v2 run. Perform this work on the analysis device, treat the
copied run as read-only, and write derived tables to a separate directory.

No video decode is required. The Jetson already verifies that the MP4 sample
count agrees with the camera and recording ledgers.

## 1. Qualification gates

Require the following before analyzing a run:

```text
run_status.json.state == "finalized"
run_status.json.overall_validation_passed == true
run_status.json.recording_validation_passed == true
run_manifest.json.serial.controller_protocol == "v2"
run_manifest.json.serial.alignment_required == false
diagnostics/controller_v2_summary.json.integrity_latched == false
diagnostics/controller_v2_summary.json.counts.crc_or_framing_errors == 0
diagnostics/controller_v2_summary.json.counts.conflicting_duplicates == 0
```

`alignment_validated=false` is expected for v2. It means the obsolete legacy
`CAMERA_HIGH` aligner was not run; it is not a failed validation. The v2
acquisition gates are the controller transport, `CAMERA_STOP` reconciliation,
camera integrity, recording admission, and MP4 sample-count checks recorded in
`run_status.json`.

## 2. Canonical inputs

| File | Meaning | Natural key |
| --- | --- | --- |
| `frames.csv` | One authoritative row per recorded camera frame | `(stream_id, source_sequence_index)` |
| `record_admission.csv` | Non-leaky recording-branch ledger | `(stream_id, record_frame_index)` |
| `inference/frames.csv` | Frames admitted to inference | `(stream_id, source_sequence_index)` |
| `objects.csv` | Detector/tracker observations | `observation_id` |
| `keypoints.csv` | Pose points belonging to observations | `(observation_id, keypoint_index)` |
| `diagnostics/controller_v2.jsonl` | Durable CRC-checked controller records | `(boot_id, sequence)` |
| `diagnostics/controller_v2_summary.json` | Controller transport integrity summary | one per run |
| `serial.csv` | Compatibility export plus host lifecycle markers | physical row order |

The JSONL journal—not `serial.csv`—is the source of truth for v2 controller
records. `serial.csv` remains useful for human inspection and host-originated
markers.

`frames.csv` is the spine of frame-level analysis. Never use inference rows as
the spine: inference may be absent while the recording branch remains complete.

## 3. The v2 timing model

Legacy firmware emitted `CAMERA_HIGH` and `CAMERA_LOW` for every trigger.
Protocol v2 intentionally avoids that serial load. It emits:

```text
CAMERA_EPOCH       exact timestamp and count for the first trigger
CAMERA_CHECKPOINT  exact timestamp and count at a periodic checkpoint
CAMERA_STOP        exact timestamp and final trigger count
```

For the current single-camera system:

```text
controller_count = CAMERA_EPOCH.count + source_sequence_index
```

The final value must equal `CAMERA_STOP.count`. The acquisition finalizer also
requires that this count equal the source, recording-admission, frame-ledger,
and MP4 sample counts.

Anchor timestamps are exact controller measurements. Per-frame controller
timestamps between anchors are piecewise-linear reconstructions. Keep the
`controller_time_method` column in derived data so an exact anchor is never
confused with an interpolated timestamp. The camera's own
`camera_timestamp_ns` remains the exact frame-to-frame camera clock.

This distinction matters for sub-frame timing claims: v2 gives exact trigger
count identity for every frame, but only sparse exact controller timestamps.

## 4. Recommended pandas workflow

The repository includes a reusable, fail-closed loader:

```python
from pathlib import Path
from data_viz.v2_alignment import associate_events_to_frames, load_v2_run

RUN = Path("/data/squeakview/source_runs/<run_id>")
OUT = Path("/data/squeakview/analysis_results/<run_id>/alignment")
OUT.mkdir(parents=True, exist_ok=True)

run = load_v2_run(RUN)
frames = run.frames
events = run.events
anchors = run.anchors
aligned_events = associate_events_to_frames(events, frames)

frames.to_parquet(OUT / "aligned_frames.parquet", index=False)
aligned_events.to_parquet(OUT / "aligned_events.parquet", index=False)
anchors.to_parquet(OUT / "controller_camera_anchors.parquet", index=False)
```

`load_v2_run` verifies the finalized status, recording validation, v2 manifest,
transport integrity summary, contiguous durable sequences, one controller boot,
camera epoch structure, frame ordinals, and final controller/frame count. It
then adds these columns to `frames.csv`:

```text
controller_count
frame_controller_us
controller_time_method        exact_anchor | piecewise_interpolated
controller_anchor_left_count
controller_anchor_right_count
controller_anchor_span_frames
frame_time_s
video_frame_index
```

`associate_events_to_frames` maps each non-camera controller message to the
immediately preceding reconstructed frame and retains
`offset_from_frame_ms`. The original journal sequence, controller timestamp,
payload, host-receipt timestamps, boot ID, and session ID remain available.

## 5. Exact inference and object joins

Join inference to frames by exact identity:

```python
import pandas as pd

inference = pd.read_csv(RUN / "inference" / "frames.csv", low_memory=False)
inference["inference_present"] = True

aligned_frames = frames.merge(
    inference,
    on=["stream_id", "source_sequence_index"],
    how="left",
    suffixes=("", "_inference"),
    validate="one_to_one",
)
aligned_frames["inference_present"] = (
    aligned_frames["inference_present"].fillna(False).astype(bool)
)

present = aligned_frames["inference_present"]
for column in (
    "camera_frame_id", "camera_timestamp_ns", "gst_pts_ns", "raw_frame_index"
):
    assert aligned_frames.loc[present, column].eq(
        aligned_frames.loc[present, f"{column}_inference"]
    ).all(), f"inference identity mismatch: {column}"
```

Join objects with `(stream_id, source_sequence_index)` and validate
`camera_frame_id`. Join keypoints to objects using `observation_id`, then
cross-check their duplicated stream, frame, camera, track, class, and object
fields. Never fuzzy-match inference with timestamps.

## 6. Keep normalized tables

The relationships are one-to-many:

```text
one camera frame
  -> zero or one inference-frame row
  -> zero or more controller events
  -> zero or more objects
       -> zero or more keypoints
```

A direct wide join creates a Cartesian multiplication and corrupts event and
object counts. Keep normalized Parquet tables and join only what an analysis
needs. If a long-format export is required, use explicit `FRAME`, `BEHAVIOR`,
and `OBJECT` record types and aggregate keypoints per object first.

## 7. Large runs

Install a Parquet engine with pandas on the analysis device:

```bash
python -m pip install pandas pyarrow
```

Frames, anchors, and controller events are normally small enough for memory.
Read `objects.csv` and especially `keypoints.csv` in chunks:

```python
frame_lookup = frames[[
    "stream_id", "source_sequence_index", "raw_frame_index",
    "camera_frame_id", "controller_count", "frame_controller_us",
    "controller_time_method", "frame_time_s",
]]

objects_out = OUT / "aligned_objects.parquet"
objects_out.mkdir(exist_ok=True)
for part, objects in enumerate(
    pd.read_csv(RUN / "objects.csv", chunksize=1_000_000)
):
    aligned = objects.merge(
        frame_lookup,
        on=["stream_id", "source_sequence_index"],
        how="left",
        suffixes=("", "_frame"),
        validate="many_to_one",
        indicator=True,
    )
    assert aligned["_merge"].eq("both").all()
    assert aligned["camera_frame_id"].eq(
        aligned["camera_frame_id_frame"]
    ).all()
    aligned.drop(columns="_merge").to_parquet(
        objects_out / f"part-{part:05d}.parquet", index=False
    )
```

A directory of numbered Parquet parts is one logical dataset and keeps peak
memory bounded. The copied CSV and JSONL files remain the canonical evidence.

## 8. Required downstream checks

Record these checks with every derived dataset:

- the source run was finalized and production eligible;
- MP4, source, recording-admission, frame-ledger, and controller-stop counts
  agree;
- the durable controller journal has one boot and contiguous stored sequences;
- camera anchors have increasing unique counts and timestamps;
- every frame has one controller count and a declared timing method;
- frame order is strictly increasing by `raw_frame_index`;
- inference joins have no duplicate frame keys;
- every object references an existing frame;
- every keypoint references an existing `observation_id`;
- duplicated identity fields agree with their parent tables;
- source-run files remain unchanged.

Missing inference is not automatically a recording failure. Missing canonical
frames, a controller/frame count mismatch, a controller boot boundary, or a
durable v2 transport integrity failure is an acquisition-integrity failure.

## 9. Legacy runs

The old `scripts/align_run_outputs.py` utility and `alignment_summary.json`
workflow are retained only for historical runs containing per-frame
`CAMERA_HIGH` records. Do not run that legacy aligner on protocol-v2 data.

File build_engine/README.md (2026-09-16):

# Project Model Builder

Model construction is part of SqueakView's pre-acquisition Project Setup UI.
The former notebook implementation has been retired so build behavior cannot
diverge from the operator workflow.

Launch SqueakView normally:

```bash
bash squeakview.sh
```

After choosing or creating a project, Project Setup displays the checkpoint/YAML
pairs under that project's `model_sources/` directory. Select a source and press
**Build Model**. New projects contain independent MouseHouse v2 and stock YOLO
pose sources, with MouseHouse v2 preselected.

The setup application starts a separate worker process which:

1. acquires the project's exclusive writer lock;
2. removes only stale staging for the selected package;
3. exports the device-local FP16 TensorRT engine and ONNX graph;
4. validates the YOLO26 pose contract and executes one bounded `trtexec` pass;
5. writes schema-3 package provenance and artifact identities;
6. atomically publishes the complete package; and
7. selects it as the project default.

The existing published package is preserved if export or validation fails.
Cancellation terminates the complete worker process group; an unpublished
staging directory is safely recovered on the next attempt.

The setup UI does not import PyTorch, Ultralytics, TensorRT, or CUDA. After a
successful build it waits for the worker to exit, reports that GPU resources
have been released, and only then allows the acquisition supervisor to start.
No manual kernel restart, cache clearing, swap manipulation, or reboot is
required. Bounded build logs are retained under
`~/.local/state/SqueakView/logs/` and can also be copied directly from Project
Setup.

The retained `build_engine.ipynb` contains only a migration notice and no
executable build path. For diagnostics or automation, the same isolated worker
can be invoked directly:

```bash
.venv/bin/python -m squeakview.apps.model_builder \
  --project "$HOME/Documents/SqueakView Projects/My Project" \
  --source mousehouse_v2 \
  --model-name mousehouse_v2
```

Normal operators should use Project Setup rather than this command.

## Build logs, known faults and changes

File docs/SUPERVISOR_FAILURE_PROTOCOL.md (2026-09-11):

# Durable Supervisor Failure Qualification Protocol

This protocol validates that loss of the mandatory GUI or termination of the
durable supervisor cannot leave scientific acquisition running headlessly. It
is destructive qualification, never a production-data procedure. Use a test
subject/input, remain at the Jetson, and verify the controller has a physical
safe state before beginning.

The guarded helper is `scripts/inject_supervisor_failure.py`. It never uses
`pgrep`, process-name matching across the machine, shell globs, or process
groups. Its default is inspection-only. Before it can send one signal, it
requires and rechecks:

- the explicit supervisor PID and Linux `/proc` start-time ticks;
- the exact target PID and start-time ticks printed by a prior dry run;
- same-user ownership and direct supervisor parentage;
- the supervisor, GUI, and capture command-line identities;
- exactly one GUI and exactly one capture child for the explicit run directory;
- the exact expected lifecycle phase and, during post-capture work, its exact
  persisted finalization stage;
- durable-supervisor ownership in `run_status.json`;
- qualification-only environment and non-production provenance.

PID start time is required because Linux can reuse a PID. Any changed identity,
phase, relationship, metadata, duplicate process, missing process, or malformed
input aborts without signaling. The remaining scheduler-scale race between a
final `/proc` check and `kill(2)` cannot be eliminated through a PID-number API;
therefore run this only on the dedicated qualification Jetson with no unrelated
SqueakView processes. Do not use `kill`, `pkill`, or `killall` manually.

## Preparation

Run the normal preflight, connect the test controller and camera, and launch the
application with the explicit qualification gate:

```bash
SQUEAKVIEW_ENABLE_SUPERVISOR_FAILURE_INJECTION=1 \
  bash squeakview.sh
```

The launcher prints the supervisor PID. Every run created by this supervisor is
marked `production_eligible: false` with the
`supervisor_failure_injection` disqualifier. Do not collect production data in
this application session.

For scheduler-independent boundary placement, select exactly one bounded
qualification barrier before launching. Barriers are inert unless the failure
gate above is also exactly `1`; an invalid selection or timeout fails startup.
The default hold is 15 seconds and the hard maximum is 60 seconds, after which
the barrier releases itself so a missed injection cannot hang collection:

```bash
SQUEAKVIEW_ENABLE_SUPERVISOR_FAILURE_INJECTION=1 \
SQUEAKVIEW_SUPERVISOR_FAILURE_BARRIER=after_spawn_before_ready \
SQUEAKVIEW_SUPERVISOR_FAILURE_BARRIER_TIMEOUT_S=30 \
  bash squeakview.sh
```

Supported barriers are `pre_capture`, `after_spawn_before_ready`, and
`finalizer:capture_reconciliation`, `finalizer:inference_admission`,
`finalizer:recording_validation`, or `finalizer:streaming_alignment`. The first
holds after required run metadata exists but before serial/capture setup. The
second holds after the capture child is supervisor-owned but before readiness
can arm the controller. Finalizer barriers hold immediately after the named
phase/stage is persisted. GUI loss cancels startup barriers; every barrier also
self-releases at its deadline. The gate continues to mark every such run
non-production even when no signal reaches the barrier.

Configure and start a short run through the mandatory GUI. Wait until the GUI
shows Recording. Record the absolute run directory and the supervisor PID.

## Dry run and explicit identity capture

The following command only inspects and prints a JSON plan:

```bash
.venv/bin/python scripts/inject_supervisor_failure.py \
  --action gui-terminate \
  --supervisor-pid SUPERVISOR_PID \
  --run-dir /absolute/path/to/run \
  --expected-phase recording
```

For a selected barrier, let the helper boundedly wait for the exact persisted
state instead of racing a brief stage:

```bash
.venv/bin/python scripts/inject_supervisor_failure.py \
  --action gui-terminate \
  --supervisor-pid SUPERVISOR_PID \
  --run-dir /absolute/path/to/run \
  --expected-phase starting \
  --expected-barrier after_spawn_before_ready \
  --wait-timeout 45
```

The wait is capped at 300 seconds and does not signal. After it observes the
exact waiting barrier, the helper performs all existing UID, parent/child,
argv, run-directory, non-production, and PID start-time checks. Execution still
requires a separate invocation with the printed exact identities,
`--execute`, and the confirmation phrase. For `pre_capture`, the helper proves
there is no capture or finalizer child; for `after_spawn_before_ready`, it
requires the exact run-bound capture child. Finalizer barriers retain the exact
post-run-child and phase/stage checks.

Confirm that `supervisor`, `gui`, `capture`, `run_dir`, and `phase` describe the
intended test. Preserve the printed supervisor `start_ticks`, target `pid`, and
target `start_ticks` in the qualification notes. The dry run always ends with
`DRY RUN: no signal sent`.

## Execute one fault

Repeat the same command with all three values copied exactly from the dry run:

```bash
.venv/bin/python scripts/inject_supervisor_failure.py \
  --action gui-terminate \
  --supervisor-pid SUPERVISOR_PID \
  --supervisor-start-ticks SUPERVISOR_START_TICKS \
  --target-pid TARGET_PID \
  --target-start-ticks TARGET_START_TICKS \
  --run-dir /absolute/path/to/run \
  --expected-phase recording \
  --execute \
  --confirm SUPERVISOR-FAILURE-QUALIFICATION
```

Run only one fault per application session and use a new run for each case:

- `gui-terminate` sends `SIGTERM` to the verified GUI. IPC lease loss must make
  the supervisor fail and finalize the run.
- `gui-freeze` sends `SIGSTOP` to the verified GUI. The heartbeat lease must
  expire, after which the supervisor fails/finalizes and forcibly cleans up the
  stopped GUI if normal termination cannot complete.
- `supervisor-terminate` sends `SIGTERM` to the verified supervisor. Its minimal
  signal handler requests fail-closed shutdown; this is not a `SIGKILL` test.

For active acquisition, supported phases are `starting`, `recording`, and
`stopping`; the helper requires one exact capture child and no post-run worker.
For post-capture work, the helper instead requires that capture is absent and
that exactly one direct supervisor-owned `squeakview.apps.inference.post_run`
worker names the run directory. Use both the persisted phase and stage:

```bash
.venv/bin/python scripts/inject_supervisor_failure.py \
  --action gui-terminate \
  --supervisor-pid SUPERVISOR_PID \
  --run-dir /absolute/path/to/run \
  --expected-phase finalizing \
  --expected-stage capture_reconciliation
```

The supported exact post-capture cells are:

| Phase | Required stage |
|---|---|
| `finalizing` | `capture_reconciliation` |
| `finalizing` | `inference_admission` (inference-enabled runs only) |
| `finalizing` | `recording_validation` |
| `analyzing` | `streaming_alignment` (triggered, serial-enabled runs only) |

Copy the dry-run identities into the execute command exactly as for an active
capture and include the same `--expected-stage` value. Stages can be brief;
failure to catch one is not permission to weaken the checks. Use a sufficiently
long qualification run and repeat from a new run.

GUI lease loss after ordered capture closure is intentionally different from
loss during acquisition. The supervisor closes the lease immediately and exits
nonzero, but the command worker already owns the lifecycle operation lock. The
client-loss finalizer waits for the in-progress bounded post-run worker rather
than interrupting validation and then observes the terminal backend state. Thus
post-capture analysis may continue without the GUI, but camera acquisition and
controller pulses may not. This exact serialization is covered by the
supervisor lifecycle tests; the on-device cells must verify it for every stage
above.

Do not test `SIGKILL` on the supervisor while a controller can generate pulses.
An uncatchable supervisor death cannot execute ordered controller shutdown; the
capture child has a parent-death signal, but independently powered controller
failsafe behavior is a separate hardware/firmware acceptance gate.

## Required evidence and pass criteria

For each case retain the GUI and supervisor bounded logs, `run_status.json`,
`run_manifest.json`, post-run progress, controller serial CSV, capture ledger,
recording telemetry, and video validation output. Record the dry-run JSON and
the helper's signal confirmation in the qualification worksheet.

The case passes only when all applicable observations hold:

1. No recording continues without the required GUI lease.
2. Trigger/controller stop occurs before capture drain when the controller was
   started, including a required stop acknowledgement.
3. Capture exits, files are closed, and fail-closed validation/finalization
   reaches a terminal state.
4. The run remains non-production and records an actionable failure reason.
5. The supervisor exits nonzero for GUI lease loss and requested supervisor
   failure; no supervisor, GUI, capture, or post-run worker remains afterward.
6. Frame and recording ledgers explain the terminal boundary without silently
   claiming a successful scientific run.

If the helper refuses a check, preserve its error as evidence, stop manually
through the GUI when possible, and investigate. Never weaken or bypass a guard
to complete a qualification cell.

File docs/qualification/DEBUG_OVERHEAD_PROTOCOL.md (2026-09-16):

# DeepStream debug-overhead protocol

This protocol measures the acquisition overhead of SqueakView's opt-in NVIDIA
latency diagnostics. The tools only inspect completed GUI-launched runs. They do
not create, simulate, launch, resume, or modify a scientific run.

## Preconditions

- Select one canonical case with
  `.venv/bin/python scripts/qualify_matrix.py --list-cases`.
- Use one reviewed `validated: true` qualification-limits file for both runs.
- Use the same Jetson, software commit, model package, native plugins, camera,
controller, capture configuration, preview state, named nvpmodel mode, and
qualification case.
- Treat every `qualification/...` path in this procedure as relative to the
  active scientific project, never the application repository.
- Plan comparable durations. The default comparison tolerance is the larger of
  five seconds or 1% of the longer run.

Select the project before using any command in this protocol:

```bash
export SQUEAKVIEW_PROJECT="/absolute/path/to/My Project"
```

The checked-in limits profile is measurement-only and cannot satisfy these
preconditions. Do not mark it validated simply to obtain a result.

The checked-in
`$SQUEAKVIEW_PROJECT/qualification/debug_overhead_thresholds.v1.yaml` is likewise an unapproved,
measurement-only template. Its seven exact metric keys each show the supported
`max_increase` and `max_percent_increase` bounds. Leave unused bounds null, but
an approved profile must provide at least one finite nonnegative bound for every
metric. Copy it to a separately reviewed, versioned file and set `approved: true`
only after the matched evidence has been reviewed; never approve the template in
place merely to obtain a passing comparison.

## Acquire the pair through the GUI

Export the same backend-enforced binding for both launches:

```bash
export SQUEAKVIEW_QUALIFICATION_CASE_ID='<case-id>'
# Optional only for a deliberate alternate matrix:
# export SQUEAKVIEW_QUALIFICATION_MATRIX='/absolute/path/to/matrix.yaml'
```

Launch and complete the baseline with the debug profile explicitly off:

```bash
export SQUEAKVIEW_DEEPSTREAM_DEBUG_PROFILE=0
bash squeakview.sh
```

Wait for terminal finalization, then exit that GUI/supervisor before changing
its environment. Qualify the completed baseline:

```bash
.venv/bin/python scripts/qualify_run.py /absolute/path/to/baseline-run \
  --limits "$SQUEAKVIEW_PROJECT/qualification/<validated-limits>.yaml"
```

Launch a new GUI/supervisor with the debug profile on, reproduce the same bound
case and duration, and wait for terminal finalization:

```bash
export SQUEAKVIEW_DEEPSTREAM_DEBUG_PROFILE=1
bash squeakview.sh
.venv/bin/python scripts/qualify_run.py /absolute/path/to/debug-run \
  --limits "$SQUEAKVIEW_PROJECT/qualification/<validated-limits>.yaml" \
  --allow-debug-profile
```

The profile also attaches NVIDIA's shipped `measure_latency_probe` and
`measure_fps_probe` downstream of the leaky inference work. Preflight requires
stable regular probe modules and records their size and SHA-256 identities.
When `NVDS_ENABLE_LATENCY_MEASUREMENT` is truthy, the raw FLIR source adds
NVIDIA's public reference-timestamp metadata immediately after setting PTS/DTS,
using the real source element name and its acquisition-local source sequence.
The production/default source path does not add this metadata. NVIDIA's API
returns no success status and documents decoder names as the standard latency
anchors, so this does not by itself prove frame-latency output for the raw-source
graph. Debug-run qualification remains incomplete/failed unless the bounded
DeepStream log has valid structured frame and component latency records, finite
Service Maker FPS evidence, and no truncation. A short GUI-launched on-device run
must demonstrate that behavior before the instrumentation is accepted.

## Compare and retain evidence

Run the Qt-free checker with an explicit case guard and durable output path:

```bash
.venv/bin/python scripts/compare_debug_overhead.py \
  /absolute/path/to/baseline-run \
  /absolute/path/to/debug-run \
  --case-id '<case-id>' \
  --thresholds "$SQUEAKVIEW_PROJECT/qualification/<reviewed-approved-debug-overhead-thresholds>.yaml" \
  --output "$SQUEAKVIEW_PROJECT/qualification/results/<pair-id>-debug-overhead.json"
```

The checker fails closed unless both runs are successfully terminal, owned by
the durable supervisor, carry identical manifest/status qualification bindings,
have opposite debug states, pass the correct qualification modes, use identical
validated limits, runtime/config/model/source identities, and meet duration and
latency-log requirements. The report retains both run paths, qualification
summary identities, and the hashed source-evidence references it consumed.

Without explicitly approved overhead thresholds, a valid comparison is
`incomplete`, not passed. Thresholds bound increases only and must cover every
reported metric. A single pair characterizes that pair; use repeated,
counterbalanced runs and scientific review before approving a general profile.
Retain the report, threshold document, limits document, matrix, and both entire
immutable run directories together.

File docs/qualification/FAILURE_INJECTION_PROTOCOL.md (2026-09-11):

# Failure-injection qualification protocol

Failure injection is disabled by default and every injected run is permanently
marked non-production. Use dedicated test storage and never reuse an injected
run as scientific evidence or a sustained-matrix cell.

Create one JSON plan per run:

```json
{
  "schema_version": "1.0",
  "target": "flir_source",
  "kind": "source_read",
  "after_frames": 30,
  "stream_id": 0,
  "delay_us": 0
}
```

Launch the normal GUI from a standalone terminal with the qualification gate
and selected plan:

```bash
SQUEAKVIEW_ENABLE_FAILURE_INJECTION=1 \
SQUEAKVIEW_FAILURE_PLAN=/absolute/path/to/plan.json \
bash squeakview.sh
```

Supported target/kind pairs are:

| Target | Kinds |
|---|---|
| `flir_source` | `source_read`, `source_incomplete`, `capture_ledger_write` |
| `record_queue` | `stall` |
| `encoder` | `error` |
| `muxer` | `error` |
| `filesink` | `error`, `disk_full` |
| `serial_controller` | `read_error`, `write_error`, `ledger_write_error` |
| `shutdown` | `stop_ack_timeout`, `capture_exit_unconfirmed`, `finalizer_timeout` |

`after_frames` is the exact number of successful frames/serial operations
before a source, recording, or serial fault begins, with one explicit
exception: `filesink/disk_full` redirects the selected sink to `/dev/full`,
which fails on its first write. It is therefore immediate-only and requires
`after_frames: 1` as a schema sentinel; it does not claim that one frame was
successfully written. Use `filesink/error` for a delayed filesink-boundary
fault. For `record_queue/stall`, set `delay_us` from 1 through 10,000,000; it is
zero for every other target. Shutdown injections occur at their named boundary
and still require `after_frames` to be at least one for the version-1 schema.

For each target, retain the plan, manifest, status, ledgers, MP4/full-decode
result, operator log, and diagnostic telemetry. Acceptance requires:

- nonzero/failure terminal status and `production_eligible: false`;
- no success claim without a concrete capture exit and post-run validation;
- no silent source-to-recording discrepancy;
- no telemetry eviction presented as frame integrity;
- bounded TERM/KILL escalation for a stuck process; and
- a subsequent uninjected short GUI run that validates normally.

Serial cases require the physical controller and cannot be substituted with a
mock for on-device acceptance. The sudden-power case is separate and follows
`HARD_POWER_LOSS_PROTOCOL.md`.

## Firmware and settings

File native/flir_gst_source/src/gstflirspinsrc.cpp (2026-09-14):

#include <gst/base/gstpushsrc.h>
#include <gst/gst.h>
#include <gst/video/video.h>

#include <algorithm>
#include <cfloat>
#include <cmath>
#include <cstdio>
#include <cstdint>
#include <cstring>
#include <iomanip>
#include <optional>
#include <sstream>
#include <string>
#include <stdexcept>
#include <vector>

#include "Spinnaker.h"
#include "SpinGenApi/SpinnakerGenApi.h"
#include "gstnvdsmeta.h"
#include "nvds_latency_meta.h"
#include "nvdsmeta.h"

using Spinnaker::CameraList;
using Spinnaker::CameraPtr;
using Spinnaker::ChunkData;
using Spinnaker::ImagePtr;
using Spinnaker::ImageProcessor;
using Spinnaker::PixelFormat_Mono8;
using Spinnaker::System;
using Spinnaker::SystemPtr;
using Spinnaker::GenApi::CBooleanPtr;
using Spinnaker::GenApi::CCommandPtr;
using Spinnaker::GenApi::CEnumEntryPtr;
using Spinnaker::GenApi::CEnumerationPtr;
using Spinnaker::GenApi::CFloatPtr;
using Spinnaker::GenApi::CIntegerPtr;
using Spinnaker::GenApi::CStringPtr;
using Spinnaker::GenApi::INodeMap;
using Spinnaker::GenApi::IsAvailable;
using Spinnaker::GenApi::IsReadable;
using Spinnaker::GenApi::IsWritable;

namespace {

constexpr guint DEFAULT_WIDTH = 1440;
constexpr guint DEFAULT_HEIGHT = 1080;
constexpr guint DEFAULT_FPS = 30;
constexpr guint DEFAULT_TIMEOUT_MS = 1000;
constexpr guint DEFAULT_MAX_CONSECUTIVE_TIMEOUTS = 10;
constexpr const char* DEFAULT_METADATA_PROFILE = "scientific";
constexpr char FLIR_FRAME_META_DESCRIPTOR[] = "SQUEAKVIEW.FLIR.FRAME_META.v1";

enum {
  PROP_0,
  PROP_CAMERA_INDEX,
  PROP_WIDTH,
  PROP_HEIGHT,
  PROP_FPS,
  PROP_PIXEL_FORMAT,
  PROP_TRIGGER,
  PROP_TRIGGER_ACTIVATION,
  PROP_EXPOSURE_US,
  PROP_GAIN,
  PROP_TIMEOUT_MS,
  PROP_DROP_INCOMPLETE,
  PROP_BUFFER_HANDLING,
  PROP_STREAM_BUFFER_COUNT,
  PROP_CAMERA_SERIAL,
  PROP_METADATA_PROFILE,
  PROP_MAX_CONSECUTIVE_TIMEOUTS,
  PROP_CAPTURE_LOG_PATH,
  PROP_FRAME_MANIFEST_PATH,
  PROP_CAMERA_TELEMETRY_PATH,
  PROP_ERROR_LOG_PATH,
  PROP_CAMERA_RUNTIME_PATH,
  PROP_FAULT_AFTER_FRAMES,
  PROP_FAULT_KIND,
};

struct _GstFlirSpinSrc {
  GstPushSrc parent;

  guint camera_index;
  guint width;
  guint height;
  guint fps;
  gchar* pixel_format;
  gboolean trigger;
  gchar* trigger_activation;
  gdouble exposure_us;
  gdouble gain;
  guint timeout_ms;
  gboolean drop_incomplete;
  gchar* buffer_handling;
  guint stream_buffer_count;
  gchar* camera_serial;
  gchar* metadata_profile;
  guint max_consecutive_timeouts;
  gchar* capture_log_path;
  FILE* capture_log;
  gchar* frame_manifest_path;
  FILE* frame_manifest;
  gchar* camera_telemetry_path;
  FILE* camera_telemetry;
  gchar* error_log_path;
  FILE* error_log;
  gchar* camera_runtime_path;
  guint64 fault_after_frames;
  gchar* fault_kind;
  gboolean fault_injected;
  gboolean latency_reference_enabled;

  guint actual_width;
  guint actual_height;
  gdouble actual_fps;
  gdouble actual_exposure_us;
  gdouble actual_gain_db;
  guint64 frame_count;
  guint64 camera_timestamp_base;
  guint64 last_frame_id;
  guint64 last_stream_frame_id;
  gboolean have_last_stream_frame_id;
  GstClockTime start_time;
  GstClockTime frame_duration;
  gboolean have_camera_timestamp_base;
  gboolean have_last_frame_id;
  gint stopping;
  gboolean acquisition_started;
  gboolean chunks_enabled;
  guint consecutive_timeouts;
  guint64 total_timeouts;
  guint64 total_incomplete;
  guint64 total_frame_gaps;
  guint64 total_crc_failures;
  guint64 actual_stream_buffer_count;
  gchar* resolved_serial;
  gchar* device_model;
  gchar* firmware_version;
  gchar* actual_pixel_format;
  gchar* enabled_chunks;
  guint64 timestamp_increment_ns;
  gboolean have_timestamp_latch;
  guint64 timestamp_latch_value;
  guint64 latch_host_monotonic_before_ns;
  guint64 latch_host_monotonic_after_ns;
  guint64 latch_host_unix_before_ns;
  guint64 latch_host_unix_after_ns;
  guint64 last_telemetry_frame;

  SystemPtr* system;
  CameraList* camera_list;
  CameraPtr* camera;
  ImageProcessor* processor;
};

struct _GstFlirSpinSrcClass {
  GstPushSrcClass parent_class;
};

}  // namespace

using GstFlirSpinSrc = _GstFlirSpinSrc;
using GstFlirSpinSrcClass = _GstFlirSpinSrcClass;

#define GST_TYPE_FLIR_SPIN_SRC (gst_flir_spin_src_get_type())
#define GST_FLIR_SPIN_SRC(obj) \
  (G_TYPE_CHECK_INSTANCE_CAST((obj), GST_TYPE_FLIR_SPIN_SRC, GstFlirSpinSrc))

G_DEFINE_TYPE(GstFlirSpinSrc, gst_flir_spin_src, GST_TYPE_PUSH_SRC)

static GstStaticPadTemplate src_template = GST_STATIC_PAD_TEMPLATE(
    "src",
    GST_PAD_SRC,
    GST_PAD_ALWAYS,
    GST_STATIC_CAPS(
        "video/x-raw, "
        "format = (string) GRAY8, "
        "width = (int) [ 1, 2147483647 ], "
        "height = (int) [ 1, 2147483647 ], "
        "framerate = (fraction) [ 0/1, 2147483647/1 ]"));

static std::string spinnaker_exception_message(const Spinnaker::Exception& exc) {
  std::ostringstream oss;
  oss << exc.what();
  return oss.str();
}
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

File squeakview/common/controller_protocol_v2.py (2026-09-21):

from __future__ import annotations

"""MouseHouse controller protocol-v2 framing and durable journal support."""

import json
import os
import struct
import threading
import zlib
from dataclasses import dataclass
from enum import IntEnum
from pathlib import Path
from typing import Any


VERSION = 2
HEADER = struct.Struct("<BBHQIQQH")
HEADER_SIZE = HEADER.size
CRC = struct.Struct("<I")
MAX_PAYLOAD_SIZE = 384
MAX_DECODED_SIZE = 422
MAX_ENCODED_SIZE = 425

FLAG_RELIABLE = 0x0001
FLAG_RETRANSMISSION = 0x0002
FLAG_INTEGRITY_LATCHED = 0x0004


class MessageType(IntEnum):
    EVENT = 1
    COMMAND_RESULT = 2
    CAMERA_EPOCH = 3
    CAMERA_CHECKPOINT = 4
    CAMERA_STOP = 5
    TRANSPORT_STATUS = 6
    INTEGRITY_FAULT = 7
    DIAGNOSTIC = 8


class ProtocolV2Error(ValueError):
    """A controller frame is malformed or violates the v2 contract."""


@dataclass(frozen=True, slots=True)
class Frame:
    message_type: int
    flags: int
    boot_id: int
    session_id: int
    sequence: int
    monotonic_us: int
    payload: bytes
    decoded: bytes

    @property
    def reliable(self) -> bool:
        return bool(self.flags & FLAG_RELIABLE)

    @property
    def retransmission(self) -> bool:
        return bool(self.flags & FLAG_RETRANSMISSION)

    @property
    def integrity_latched(self) -> bool:
        return bool(self.flags & FLAG_INTEGRITY_LATCHED)

    @property
    def text(self) -> str:
        try:
            return self.payload.decode("utf-8", errors="strict")
        except UnicodeDecodeError as exc:
            raise ProtocolV2Error(f"payload is not valid UTF-8: {exc}") from exc

    def identity(self) -> tuple[object, ...]:
        """Identity that deliberately ignores the retransmission flag and CRC."""

        return (
            self.message_type,
            self.flags & ~FLAG_RETRANSMISSION,
            self.session_id,
            self.sequence,
            self.monotonic_us,
            self.payload,
        )


def crc32(data: bytes) -> int:
    return zlib.crc32(data) & 0xFFFFFFFF


def cobs_decode(encoded: bytes) -> bytes:
    if not encoded:
        raise ProtocolV2Error("empty COBS frame")
    output = bytearray()
    index = 0
    while index < len(encoded):
        code = encoded[index]
        if code == 0:
            raise ProtocolV2Error("zero byte inside COBS body")
        index += 1
        end = index + code - 1
        if end > len(encoded):
            raise ProtocolV2Error("COBS code exceeds encoded frame")
        output.extend(encoded[index:end])
        index = end
        if code != 0xFF and index < len(encoded):
            output.append(0)
    return bytes(output)


def cobs_encode(decoded: bytes) -> bytes:
    """Reference encoder used by tests and diagnostic tooling."""

    output = bytearray(b"\x00")
    code_index = 0
    code = 1
    for byte in decoded:
        if byte == 0:
            output[code_index] = code
            code_index = len(output)
            output.append(0)
            code = 1
        else:
            output.append(byte)
            code += 1
            if code == 0xFF:
                output[code_index] = code
                code_index = len(output)
                output.append(0)
                code = 1
    output[code_index] = code
    output.append(0)
    return bytes(output)


def decode_frame(encoded: bytes) -> Frame:
    if len(encoded) + 1 > MAX_ENCODED_SIZE:
        raise ProtocolV2Error(
            f"encoded frame exceeds {MAX_ENCODED_SIZE} bytes including delimiter"
        )
    decoded = cobs_decode(encoded)
    if len(decoded) < HEADER_SIZE + CRC.size:
        raise ProtocolV2Error("decoded frame is shorter than header plus CRC")
    if len(decoded) > MAX_DECODED_SIZE:
        raise ProtocolV2Error(f"decoded frame exceeds {MAX_DECODED_SIZE} bytes")
    (
        version,
        message_type,
        flags,
        boot_id,
        session_id,
        sequence,
        monotonic_us,
        payload_length,
    ) = HEADER.unpack_from(decoded)
    if version != VERSION:
        raise ProtocolV2Error(f"unsupported protocol version {version}")
    if payload_length > MAX_PAYLOAD_SIZE:
        raise ProtocolV2Error(
            f"payload length {payload_length} exceeds {MAX_PAYLOAD_SIZE}"
        )
    expected = HEADER_SIZE + payload_length + CRC.size
    if len(decoded) != expected:
        raise ProtocolV2Error(
            f"decoded length {len(decoded)} does not match declared length {expected}"
        )
    expected_crc = CRC.unpack_from(decoded, HEADER_SIZE + payload_length)[0]
    actual_crc = crc32(decoded[: HEADER_SIZE + payload_length])
    if actual_crc != expected_crc:
        raise ProtocolV2Error(
            f"CRC mismatch: expected 0x{expected_crc:08x}, calculated 0x{actual_crc:08x}"
        )
    payload = decoded[HEADER_SIZE : HEADER_SIZE + payload_length]
    return Frame(
        message_type=message_type,
        flags=flags,
        boot_id=boot_id,
        session_id=session_id,
        sequence=sequence,
        monotonic_us=monotonic_us,
        payload=payload,
        decoded=decoded,
    )


def encode_frame(
    *,
    message_type: int,
    flags: int,
    boot_id: int,
    session_id: int,
    sequence: int,
    monotonic_us: int,
    payload: bytes,
) -> bytes:
    if len(payload) > MAX_PAYLOAD_SIZE:
        raise ValueError(f"payload exceeds {MAX_PAYLOAD_SIZE} bytes")
    header = HEADER.pack(
        VERSION,
        message_type,
        flags,
        boot_id,
        session_id,
        sequence,
        monotonic_us,
        len(payload),
    )
    body = header + payload
    return cobs_encode(body + CRC.pack(crc32(body)))
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

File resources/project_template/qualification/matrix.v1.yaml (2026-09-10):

schema_version: "1.0"
matrix_id: orin-nano-super-jp721-sustained-v1
description: Required scientific acquisition qualification cells.

capture_profiles:
  - id: mono8-1440x1080-30fps-1cam
    width: 1440
    height: 1080
    fps: 30
    camera_count: 1
    pixel_format: Mono8
    trigger_on: true
    trigger_activation: rising
    arduino_fps: 30
    exposure_us: 10000.0
    bitrate_kbps: 4000
    serial_enabled: true
    serial_port: /dev/ttyACM0
    serial_baud: 115200

durations:
  - id: short
    minimum_seconds: 300
  - id: one-hour
    minimum_seconds: 3600
  - id: full-duration
    minimum_seconds: 57600

inference_enabled: [true, false]
preview_enabled: [true, false]
power_modes: [25W, MAXN_SUPER]

provenance:
  require_clean_git: true
  require_same_git_commit: true
  require_same_model_identity: true
  require_same_device_identity: true
  require_same_acquisition_identity: true
  require_case_binding: true
  require_production_eligible: true

notes:
  - Export SQUEAKVIEW_QUALIFICATION_CASE_ID to the exact case before launching each cell.
  - Run every cell from the GUI launched in a standalone terminal.
  - Use SQUEAKVIEW_DISABLE_PREVIEW=1 for preview-off cells.
  - MAXN_SUPER is accepted only if telemetry proves a stable no-throttle run.
  - A cell is not complete until its run passes frame-integrity and validated limits.

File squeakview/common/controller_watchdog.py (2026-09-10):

from __future__ import annotations

"""Experimental, firmware-independent host state machine for watchdog v1.

The state machine is transport agnostic so its framing, nonce binding, bounded
waits, heartbeat policy, and fail-close behavior can be tested without opening
hardware.  It is not evidence that matching controller firmware exists.
"""

import re
import secrets
import threading
import time
import math
from dataclasses import dataclass
from typing import Callable


PROTOCOL_VERSION = 1
MIN_LEASE_MS = 100
MAX_LEASE_MS = 60_000
REQUIRED_FEATURES = frozenset(
    {
        "lease_watchdog",
        "trigger_low_failsafe",
        "session_nonce",
        "telemetry_v1",
    }
)
_NONCE_RE = re.compile(r"^[0-9a-f]{32}$")
_TOKEN_RE = re.compile(r"^[A-Za-z0-9._-]{1,128}$")
_FEATURE_RE = re.compile(r"^[A-Za-z0-9_-]{1,64}$")
_STATES = frozenset({"DISARMED", "ARMED", "WATCHDOG_TRIPPED"})
_REASONS = frozenset(
    {
        "BOOT",
        "ARM_COMMAND",
        "DISARM_COMMAND",
        "LEASE_EXPIRED",
        "USB_DISCONNECT",
        "INTERNAL_WATCHDOG",
        "INVALID_COMMAND",
    }
)
MAX_FEATURES = 32
MAX_SEQUENCE = (1 << 63) - 1
MAX_HOST_WAIT_S = 60.0


def _uint(text: str, label: str, *, maximum: int = MAX_SEQUENCE) -> int:
    if not text.isascii() or not text.isdecimal():
        raise ValueError(f"{label} must be an unsigned decimal integer")
    value = int(text)
    if value > maximum:
        raise ValueError(f"{label} exceeds {maximum}")
    return value


def _nonce(text: str) -> str:
    if _NONCE_RE.fullmatch(text) is None:
        raise ValueError("controller session nonce must be 32 lowercase hexadecimal characters")
    return text


def _host_wait_seconds(value: float) -> float:
    if isinstance(value, bool):
        raise ValueError("controller host wait must be a finite number")
    try:
        timeout = float(value)
    except (TypeError, ValueError) as exc:
        raise ValueError("controller host wait must be a finite number") from exc
    if not math.isfinite(timeout) or not 0.0 <= timeout <= MAX_HOST_WAIT_S:
        raise ValueError(
            f"controller host wait must be between 0 and {MAX_HOST_WAIT_S:g} seconds"
        )
    return timeout


@dataclass(frozen=True, slots=True)
class ControllerCapabilities:
    protocol_version: int
    session_nonce: str
    firmware_version: str
    watchdog_timeout_ms: int
    features: frozenset[str]


@dataclass(frozen=True, slots=True)
class ControllerAck:
    kind: str
    protocol_version: int
    session_nonce: str
    sequence: int
    controller_monotonic_us: int
    ttl_count: int | None = None


@dataclass(frozen=True, slots=True)
class ControllerState:
    protocol_version: int
    session_nonce: str
    state: str
    controller_monotonic_us: int
    ttl_count: int
    reason: str


def parse_capabilities(line: str) -> ControllerCapabilities | None:
    if not line.startswith("CONTROLLER_CAPS,"):
        return None
    fields = line.split(",")
    if len(fields) != 6:
        raise ValueError("CONTROLLER_CAPS must contain exactly six CSV fields")
    _, version, nonce, firmware, timeout, raw_features = fields
    protocol_version = _uint(version, "controller protocol version", maximum=255)
    session_nonce = _nonce(nonce)
    if _TOKEN_RE.fullmatch(firmware) is None:
        raise ValueError("controller firmware version is invalid")
    watchdog_timeout_ms = _uint(timeout, "controller watchdog timeout", maximum=MAX_LEASE_MS)
    if watchdog_timeout_ms < MIN_LEASE_MS:
        raise ValueError(
            f"controller watchdog timeout must be between {MIN_LEASE_MS} and {MAX_LEASE_MS} ms"
        )
    items = raw_features.split(";") if raw_features else []
    if len(items) > MAX_FEATURES:
        raise ValueError("controller capability list is too large")
    if any(_FEATURE_RE.fullmatch(item) is None for item in items):
        raise ValueError("controller capability list contains an invalid feature")
    if len(set(items)) != len(items):
        raise ValueError("controller capability list contains a duplicate feature")
    return ControllerCapabilities(
        protocol_version,
        session_nonce,
        firmware,
        watchdog_timeout_ms,
        frozenset(items),
    )


def parse_ack(line: str) -> ControllerAck | None:
    prefix = line.split(",", 1)[0]
    if prefix not in {"ACK_ARM", "ACK_HEARTBEAT", "ACK_DISARM"}:
        return None
    fields = line.split(",")
    expected = 6 if prefix in {"ACK_HEARTBEAT", "ACK_DISARM"} else 5
    if len(fields) != expected:
        raise ValueError(f"{prefix} must contain exactly {expected} CSV fields")
    protocol_version = _uint(fields[1], "ack protocol version", maximum=255)
    session_nonce = _nonce(fields[2])
    sequence = _uint(fields[3], "ack sequence")
    controller_us = _uint(fields[4], "controller monotonic clock")
    ttl_count = None
    if prefix == "ACK_HEARTBEAT":
        ttl_count = _uint(fields[5], "heartbeat TTL count")
    elif prefix == "ACK_DISARM":
        ttl_count = _uint(fields[5], "disarm TTL count")
    return ControllerAck(
        kind=prefix.removeprefix("ACK_"),
        protocol_version=protocol_version,
        session_nonce=session_nonce,
        sequence=sequence,
        controller_monotonic_us=controller_us,
        ttl_count=ttl_count,
    )


def parse_state(line: str) -> ControllerState | None:
    if not line.startswith("CONTROLLER_STATE,"):
        return None
    fields = line.split(",")
    if len(fields) != 7:
        raise ValueError("CONTROLLER_STATE must contain exactly seven CSV fields")
    _, version, nonce, state, controller_us, ttl_count, reason = fields
    if state not in _STATES:
        raise ValueError("controller state is not a v1 enumerated state")
    if reason not in _REASONS:
        raise ValueError("controller state reason is not a v1 enumerated reason")
    return ControllerState(
        _uint(version, "controller state protocol version", maximum=255),
        _nonce(nonce),
        state,
        _uint(controller_us, "controller state monotonic clock"),
        _uint(ttl_count, "controller state TTL count"),
        reason,
    )
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

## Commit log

2025-12-08 remove debug buttons in gui
2025-12-08 Fix author email
    [Cage_Base.step, Cage_Lid.step, FED3_Insert.step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]
2025-12-08 Arduino Firmware for MouseHouse Controller Board
2025-12-08 Update README with 3D printing and firmware info
    Added additional files for 3D printing and Arduino firmware. Updated installation instructions and GUI launch command.
2026-01-25 added email notification for jams and other minor debugging
    [calibration_app_config.txt, deepstream_app_config.txt]
2026-03-11 Release v1.1.0
    [Box.stl, Cage_Base.step, Cage_Lid.step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]
2026-06-04 real deepstream + flir capture without pyspin - basically a whole refactor - its also prettier
    [calibration_app_config.txt, deepstream_app_config.txt]
2026-06-10 Add Materials.md
2026-07-07 Harden local run saving and add bottle metadata capture
    [FLIR_Camera_Top_Mount.step]
2026-07-14 Harden run lifecycle and require locally built model packages
    - report actionable serial and inference failures in the operator GUI
    - track run lifecycle transitions and handle unexpected process exits
    safely
    - wait for inference readiness before starting the experiment controller
    - remove automatic/default model selection
    - validate model packages and record config and engine hashes in
    manifests
    - ship model-building inputs while ignoring generated model artifacts
    - localize DeepStream configs into each run directory
    - improve run metadata, bottle records, and post-run alignment summaries
    - validate video, frame, serial, detection, and keypoint alignment
    - add regres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
2026-07-24 • Migrate SqueakView to JetPack 7.2 and DeepStream 9.1
    - replace deprecated pyds runtime with PyServiceMaker pipelines
    - add scientific FLIR frame metadata and timestamp reconciliation
    - isolate non-leaky recording from leaky inference and GUI preview
    - add modernized YOLO26 pose export, validation, tracking, and offline replay
    - update run alignment and visualization workflows
    - remove obsolete skeleton and chunked-recording features
    - refresh tests, preflight checks, and documentation
    [gstflirspinsrc.cpp, run_context.py]
2026-07-28 SqueakView Production Readiness Update
    Release date: July 28, 2026
    Platform: JetPack 7.2 · DeepStream 9.1 · Python 3.12
    ## Highlights
    - Migrated the capture and inference pipeline to DeepStream 9.1 PyServiceMaker.
    - Reworked shutdown and post-run processing to prevent GUI crashes and long-run teardown hangs.
    - Added authoritative frame reconciliation across the FLIR source, recording branch, MP4, inference, and
    controller TTL events.
    - Added a bounded-memory post-run finalizer suitable for long recordings.
    - Modernized the operator GUI with explicit lifecycle states, live capture health, finalization progress,
    and an Events drawer.
    ## Capture and recording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
    [gstflirspinsrc.cpp, run_context.py, serial.py]
2026-07-29 Finalize long-run provenance, validation, and DGX analysis workflow
    - preserve immutable run metadata after finalization
    - warn on negative bottle intake measurements
    - simplify bounded alignment outputs and failure exit codes
    - document validated 16-hour capture behavior
    - add manual Jetson-to-DGX transfer and analysis guide
    - frame the visualization notebook as a short-run example
    - flag resumable rsync transfer for a future release
    [run_context.py]
2026-08-06 deprecate arduino firmware in favor of separate firmware packing
2026-09-01 refactor: harden scientific capture and JetPack 7.2.1 support
    - guarantee non-leaky recording while isolating preview and inference queues
    - add frame admission, recording, alignment, and acquisition-integrity ledgers
    - fail closed on serial, capture, STOP acknowledgment, and child-process errors
    - add atomic run metadata, device provenance, and partial-run finalization
    - make shutdown resilient to GUI and logging pipe failures
    - extract recording and capture policy modules
    - add explicit FFmpeg, camera, dependency, and dialout preflight checks
    - add automated Jetson setup and detached GUI launcher scripts
    - improve operator warnings, diagnostics, and persistent log capture
    - document NVIDIA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
    [capture_policy.py, device_context.py, log_mirror.py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]
2026-09-10 refactor: harden supervised scientific capture and qualification
    - move acquisition ownership into a durable GUI-supervised backend
    - prevent headless capture after GUI freezes, crashes, or disconnects
    - preserve a non-leaky, backpressured recording branch upstream of inference
    - reconcile source, admission, MP4, camera, trigger, and inference frame identities
    - add ordered EOS, container draining, finalization, and failure persistence
    - add bounded serial I/O, controller alignment, and experimental watchdog support
    - add live storage protection and recording-liveness monitoring
    - split inference, operator backend, and GUI responsibilities into testable modules
    - replace lifecycle log parsin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
    [bounded_csv.py, bounded_input.py, child_events.py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]
2026-09-11 fix: preserve bottle measurements across supervisor IPC
    Accept recursively frozen mapping payloads at the bottle artifact boundary so initial and final weights survive the durable supervisor protocol. Add normalization and supervisor regression coverage for the production launch path.
    [run_context.py]
2026-09-14 refactor: make post-run frame validation fast
    Validate MP4 sample-table totals against durable capture, admission, and controller counts without decoding, whole-file hashing, or full ledger scans during shutdown.\n\nMove frame reconstruction and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
2026-09-14 fix: restore fast scientific run finalization
    Write canonical frame and camera diagnostic evidence live during acquisition, validate finalized MP4 sample counts without full decode, restore automatic controller alignment, and mark deferred object analysis as unavailable instead of zero.
    [gstflirspinsrc.cpp]
2026-09-15 fix: finalize runs asynchronously
    Acknowledge stop requests immediately while the durable supervisor owns capture closure and post-run alignment. Keep the GUI connected until a terminal lifecycle event and cover delayed finalizers with regression tests.\n\nDocument a pandas and Parquet workflow for aligning canonical camera, controller, inference, object, and keypoint outputs on the analysis device.
2026-09-15 Add feeder jam recovery and harden shutdown IPC
    Detect latched feeder jams from FEED_JAM and NACK,FEED,JAMMED, keep feeding disabled until an authoritative ACK_CLEAR_JAM, and expose a non-blocking Clear Jam workflow with persistent operator guidance and exact serial protocol handling.
    Give supervisor event delivery an independent bounded deadline, retain concrete IPC failure details, and preserve successful durable finalization when the GUI connection is lost after Stop has already been accepted. GUI loss during startup or active acquisition remains fail-closed.
    Add coverage for jam detection, command acknowledgement and failure paths, duplicate-click suppression, unrelated serial traffic,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
    [dashboard.py, serial.py]
2026-09-16 feat: add controller clock preflight
    Validate and optionally correct the MouseHouse RTC before acquisition, preserve structured timing evidence in run outputs, and expose the result as an optional workspace card. Reset behavior counters and raster history at each new run while retaining authoritative feeder-jam state. Update project documentation and add protocol, lifecycle, and GUI coverage.
    [clock_validation.py, dashboard.py, serial.py]
2026-10-14 Fix Jetson setup checks and clarify RTC correction failures
    - Configure dialout permissions before native builds
    - Prevent false parser-symbol failures caused by SIGPIPE
    - Explain controller RTC anchor failures and add regression coverage
2026-10-19 Add VLC to Jetson setup and extend recording watchdog timeout
    - Install VLC alongside existing system dependencies
    - Increase recording stall timeout default and fallback from 8 to 30 seconds
    - Update timeout test expectations
2026-10-21 Add GUI stall diagnostics and extend heartbeat timeout to 30 seconds
    Capture thread stacks and heartbeat timing during GUI stalls using
    bounded background writes that acquisition never waits for.
    Increase the GUI heartbeat timeout from 10 to 30 seconds and add
    tests for stall capture, recovery, blocked writes, and lease expiry.
2026-10-23 Add bottle swaps, measurement history, and graceful camera shutdown
    Support fluid changes, bottle-specific lick counts, and mouse weights.
    Improve swap dialog usability and controller-state reconciliation.
    Preserve the final in-flight camera frame during shutdown.
2026-10-24 Harden acquisition against GUI crashes and heartbeat failures
    Keep recording active during GUI loss and restore the interface automatically.
    Isolate native preview rendering and keep Qt cleanup on the GUI thread.
    Fix CSV and journal lifetime races, bound presentation queues and journal memory,
    and add crash diagnostics with regression coverage.
2026-10-27 Simplify run outputs and stabilize the recording workflow
    - Consolidate primary CSVs and preserve timestamp provenance
    - Store bottle measurements and swap history in weigh_in.csv
    - Merge run status into the manifest and compress recovery logs
    - Preserve weigh-in entries through Start, Stop, and Save
    - Show save confirmation on the button and restore collapsed dock sizes
    - Fix controller v2 startup synchronization and sensor logging
    - Reorganize scripts and update legacy readers, tests, and documentation
2026-10-30 Replace per-frame capture JSONL with compact health snapshots
    - Keep per-frame timing and identity in frames.csv
    - Update validation, GUI health, drain checks, and recovery readers
    - Preserve compatibility with historical JSONL recordings
    - Add lifecycle, integrity, and long-run regression coverage
